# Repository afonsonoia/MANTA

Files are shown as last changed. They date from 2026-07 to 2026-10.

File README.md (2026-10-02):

# MANTA – Embedded AI & Vision-Guided Autonomous Flight Platform

<p align="center">
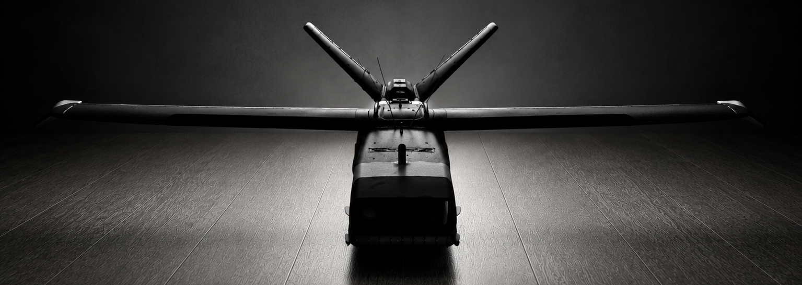
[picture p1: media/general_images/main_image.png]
MANTA Aircraft Platform
  
</p>

<p align="center">
  
  
  
  
  
  
</p>

**MANTA** is an experimental fixed-wing UAV research platform designed for investigating embedded computer vision, attitude stabilization, and autonomous navigation in GPS-denied environments.

Rather than relying on commercial black-box autopilots, MANTA is engineered from the ground up as an open, modular avionics architecture: combining low-level deterministic real-time control (ESP32) with high-level onboard perception and video recording (Raspberry Pi 3 A+ companion computer).

> **Origin of the Name**: *MANTA* is a regional term from Madeira Island, Portugal, designating the local population of the Common Buzzard (*Buteo buteo rothschildi*), a resident bird of prey known for soaring effortlessly across the island's steep oceanic mountains.

---

## In-Flight Validation & Onboard Camera Footage

MANTA has achieved fully stabilized flight under closed-loop fly-by-wire control with calibrated attitude PIDs, verified aerodynamic handling, and active onboard video recording.

The companion computer (**Raspberry Pi 3 A+**) flies onboard with a dedicated camera module, executing an autonomous power-loss-immune recording pipeline (`.mkv`) with sport shutter tuning to eliminate motor vibration artifacts and rolling shutter jello.

### Onboard Flight Video

<p align="center">
  <a href="https://www.youtube.com/watch?v=h6kUTQn7zuM&t=90s" target="_blank" rel="noopener noreferrer" title="Click to watch MANTA flight video on YouTube starting at 1:30 min">
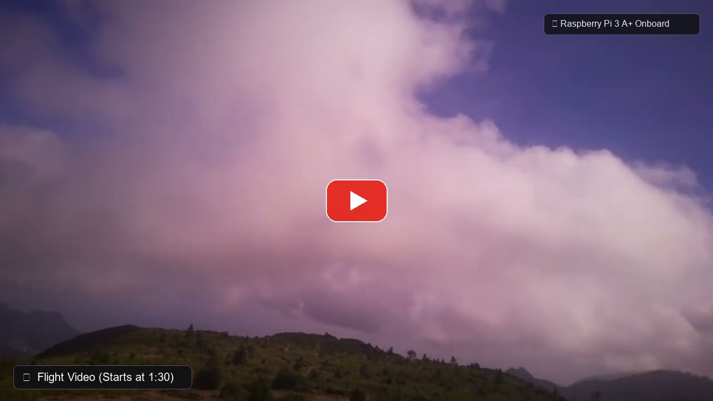
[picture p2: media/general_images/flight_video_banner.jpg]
MANTA Onboard Flight Footage (Click to Play from 1:30 min)
    
  </a>
  <br>
  <em>▶️ <b>Watch the flight video</b> — Aerial footage captured directly by the onboard Raspberry Pi 3 A+ camera during flight tests. <b><a href="https://www.youtube.com/watch?v=h6kUTQn7zuM&t=90s" target="_blank">Click here or on the image above to play on YouTube starting at 1:30 min</a></b>.</em>
</p>

### Pre-Flight Preparation & Avionics Checkout

<p align="center">
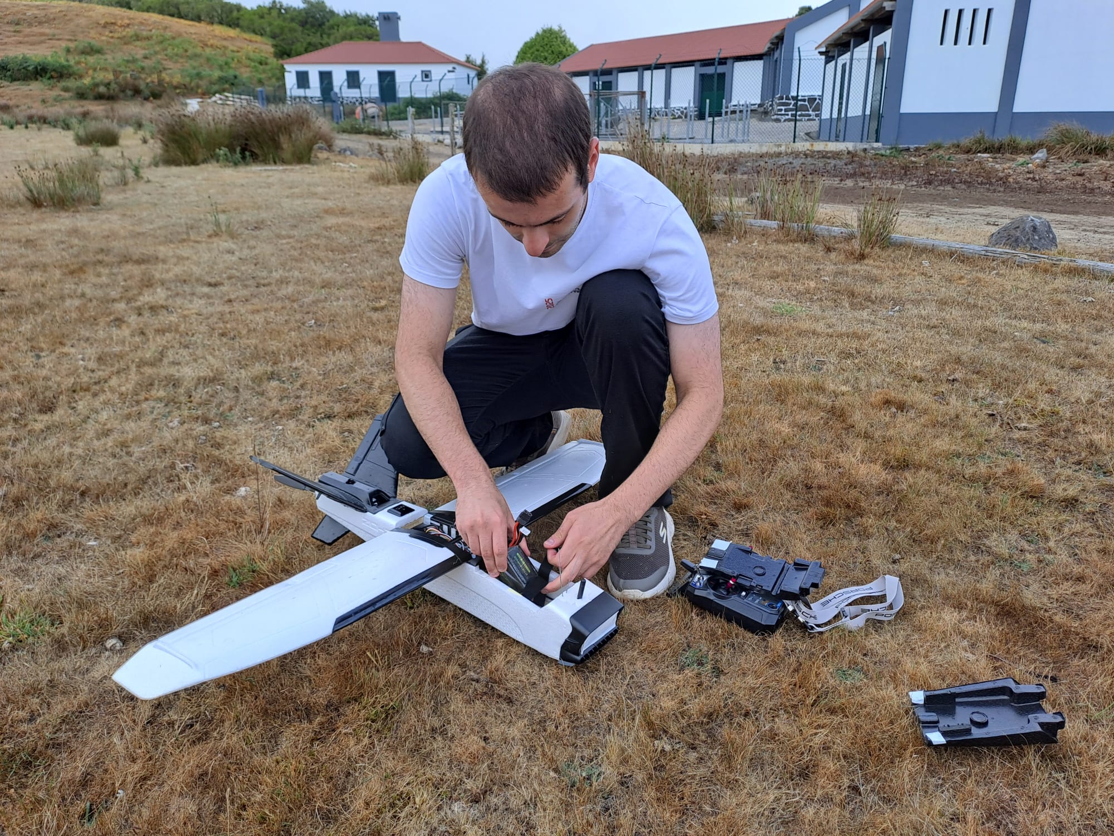
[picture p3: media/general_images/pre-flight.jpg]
Pre-Flight Avionics Check and Setup
  
  <br>
  <em>Pre-flight checkout at the flight field: LiPo battery installation, 6-axis IMU zeroing, radio link verification, and autonomous companion computer boot sequence before launch.</em>
</p>

During field operations, pre-flight checks verify the full avionics chain:
1. **Airframe & Propulsion**: 4S LiPo battery securement, Hobbywing Skywalker 40A V2 ESC throttle arming, and control horn linkage checks.
2. **IMU & Attitude Zeroing**: Static 6-axis MPU6050 accelerometer and gyroscope calibration with mounting offsets (+9.2° Pitch, +4.4° Roll).
3. **Control Surface Trims**: V-tail ruddervator and elevon zero-point verification across all 4 servos within calibrated hardware limits.
4. **LoRa Telemetry Handshake**: 20 Hz binary telemetry downlink reception and acoustic buzzer confirmation on the Ground Station ESP32.
5. **Companion Boot**: Autonomous transition of the Raspberry Pi 3 A+ into Field Mode with RF blocking and continuous video capture.

---

## Avionics & Embedded Hardware Architecture

MANTA uses a custom-manufactured dual-board shield architecture designed in KiCad, cleanly distributing high-current motor power and low-noise sensor signals while fitting into the airframe fuselage.

<p align="center">
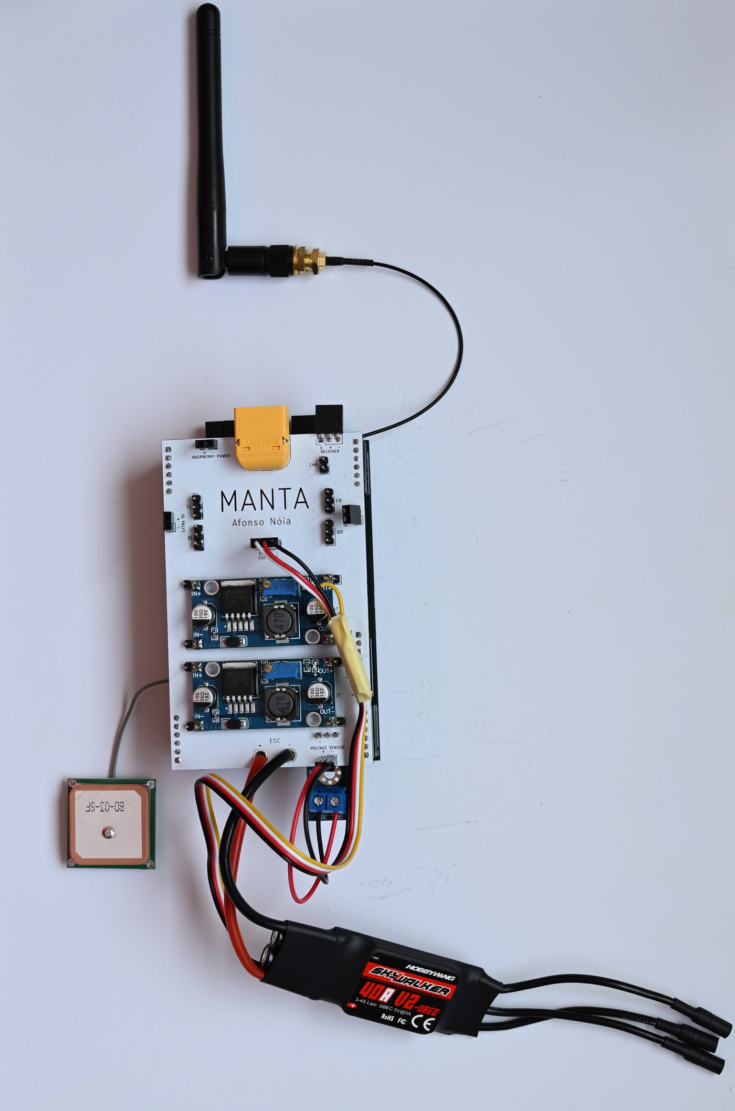
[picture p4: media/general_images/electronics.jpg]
MANTA Assembled Electronics Stack
  
  <br>
  <em>Complete assembled avionics stack: Custom dual-board PCB shield, ESP32 flight controller, LoRa 433 MHz RF link, Air530 GPS antenna, dual LM2596S switching buck converters, precision voltage divider, and Hobbywing Skywalker 40A V2-UBEC ESC.</em>
</p>

### Core Hardware Components

| Subsystem | Component | Role / Specification |
|---|---|---|
| **Flight Controller** | ESP32-WROOM-32 (240 MHz Dual-Core) | Real-time 100 Hz attitude estimation, RC receiver pulse decoding, PI-D control loops, V-tail servo mixing, and 20 Hz LoRa telemetry. |
| **Companion Computer** | Raspberry Pi 3 A+ (64-bit Quad-Core) | Camera management, high-bitrate in-flight video recording, visual place recognition (VPR), and future autonomous vision navigation. |
| **In-Flight Camera** | Sony IMX378-79 Sensor Module | High-resolution aerial video capture, 2x2 binned low-latency readout, and visual feature extraction. |
| **Inertial Measurement (IMU)** | MPU6050 (6-Axis Accel / Gyro) | High-rate attitude determination running Mahony AHRS quaternion fusion filter at 100 Hz. |
| **Barometric Altimeter** | BMP280 | Static pressure sensing, relative barometric altitude tracking, and vertical velocity estimation over I2C. |
| **RF Telemetry Link** | SX1278 LoRa Transceiver (433 MHz) | Long-range 20 Hz binary telemetry downlink (SF7, BW 250 kHz, CR 4/5, CRC16) streaming flight dynamics to the ground. |
| **Satellite Navigation** | Air530 Multi-GNSS Module | Global positioning reference, ground track velocity, and satellite constellation tracking over hardware UART. |
| **Electronic Speed Control (ESC)** | Hobbywing Skywalker 40A V2-UBEC | 3S–4S LiPo motor speed control with integrated 5V/5A switching BEC powering the avionics bus. |
| **Power Regulation** | Dual LM2596S DC-DC Regulators | Independent 5.1V / 3A power rails dedicated to the Raspberry Pi companion computer and servo bus, isolating control logic from servo voltage sag. |
| **Battery Monitoring** | Precision Calibrated Voltage Divider | Calibrated ADC sensing validated to within 0.062V of multimeter ground truth across 3S/4S voltage curves. |

### Custom Manufactured PCB Shields

<p align="center">
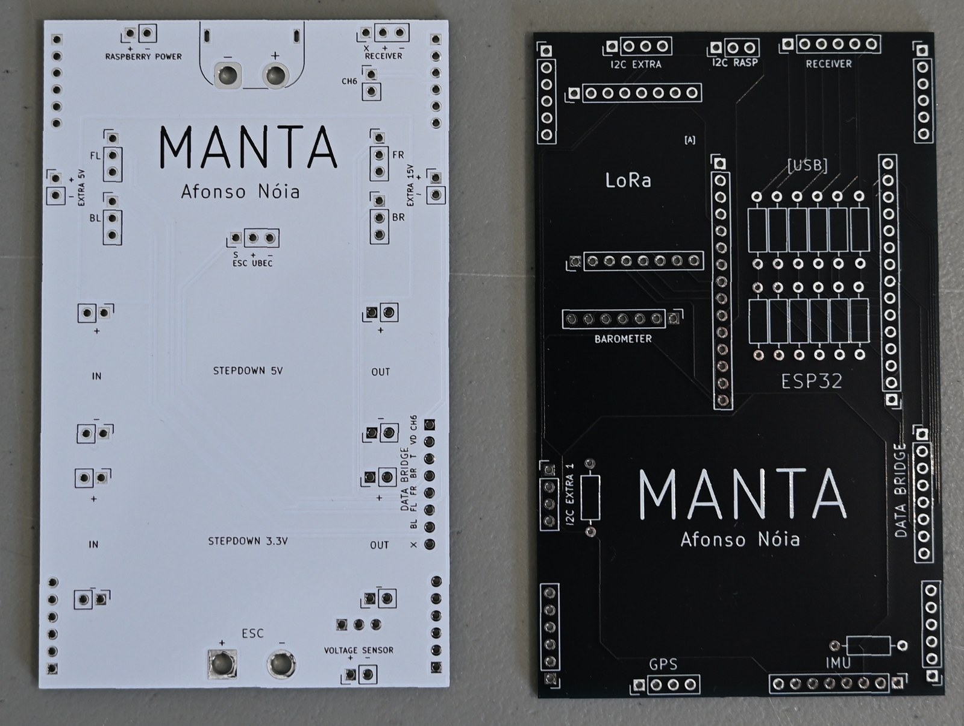
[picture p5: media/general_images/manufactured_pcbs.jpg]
Manufactured Physical PCBs
  
</p>

<p align="center">
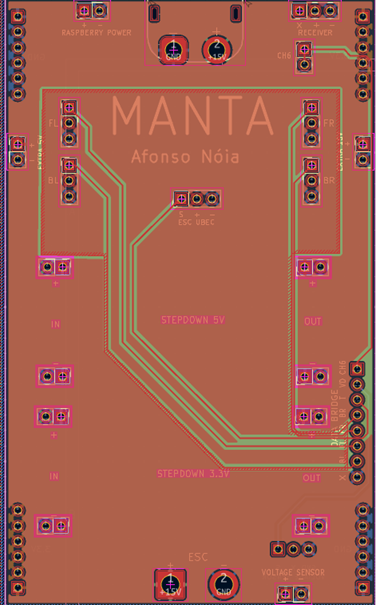
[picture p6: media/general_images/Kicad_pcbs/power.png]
PCB Power Routing
  
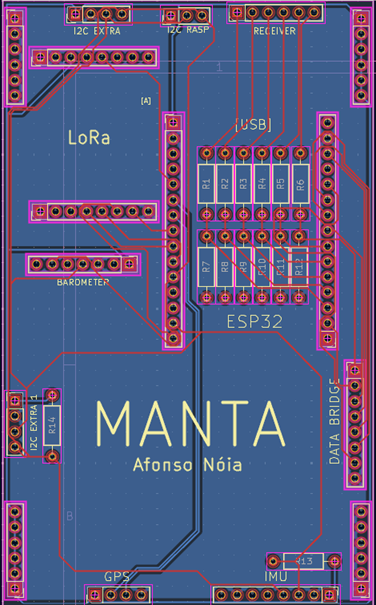
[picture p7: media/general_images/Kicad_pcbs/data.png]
PCB Data Routing
  
  <br>
  <em>KiCad Dual-Board Shield Layouts: Power Distribution Board & Data / Sensor Board</em>
</p>

- **Two-Board Architecture**: Separates noisy high-current traces (motor ESC, LiPo leads, buck regulators) on the Power Board from sensitive analog sensors (MPU6050, BMP280, LoRa SPI bus, RC receiver lines) on the Data Board.
- **Continuous Ground Pours**: Low-impedance ground returns and copper shielding prevent motor/ESC switching noise from coupling into the RF frontend or ADC measurements.

### Pinout & GPIO Mapping

```
RC Receiver Inputs:                  Servo & ESC Outputs:
  CH1 (Roll / Rollerons): Pin D39      Back Right (BR / V-Tail): Pin D13
  CH2 (Pitch / Elevator): Pin D34      Back Left  (BL / V-Tail): Pin D14
  CH3 (Throttle / ESC):   Pin D35      Front Right (FR / Flap):  Pin D27
  CH4 (Aux / Rudder):     Pin D32      Front Left  (FL / Flap):  Pin D26
  CH5 (Mode SWC + SWB):   Pin D33      Motor Throttle / ESC:     Pin D25

Buses & Peripherals:
  LoRa SX1278 (VSPI):     SCK=18, MISO=19, MOSI=23, CS=5, DIO0=4
  I2C Sensors (IMU+BMP):  SDA=21, SCL=22
  Air530 GNSS (UART2):    RX2=16, TX2=17
  Battery Voltage ADC:    Pin D36 (VP)
```

---

## Flight Control Architecture & Calibrated PIDs

MANTA utilizes a hybrid V-tail mixing scheme where Pitch is controlled by the rear ruddervators (BR/BL) and Roll is controlled by the front control surfaces (FR/FL), with elevator assist.

```mermaid
flowchart TD
    subgraph Inputs [Pilot & Sensor Inputs]
        RC[RC Receiver CH1-CH5]
        IMU[MPU6050 6-Axis IMU]
        BARO[BMP280 Barometer]
    end

    subgraph StateEst [Attitude Estimation]
        IMU --> Mahony[100 Hz Mahony AHRS Filter]
        Mahony --> Att[Pitch & Roll Euler Angles]
    end

    subgraph ControlCore [Flight Control Core]
        RC --> ModeSelect{Flight Mode Selector\nCH5 SWC + SWB}
        Att --> ModeSelect

        ModeSelect -->|Mode 1| M1[Manual Pitch + Roll Assist]
        ModeSelect -->|Mode 2| M2[FBW Pitch PI-D + FBW Roll PI-D]
        ModeSelect -->|Mode 3| M3[FBW Pitch PI-D + Adaptive Extremum Seeking Roll]

        SWB{Flaperons SWB} -->|Active| Flaps[20° Down Flaperon Governor]
    end

    subgraph Mixing [Actuator Mixer & Anti-Saturation]
        M1 & M2 & M3 --> Mixer[V-Tail & Wing Mixer]
        Flaps --> Mixer
        Mixer --> Headroom[Headroom Scaling & Anti-Saturation]
    end

    subgraph Outputs [Physical Actuators]
        Headroom --> Servos[BR / BL / FR / FL Servos + ESC]
    end
```

### Flight Modes (Transmitter CH5: SWC + SWB)

The pilot switches flight modes in real time via transmitter switches **SWC** (3-position mode switch) and **SWB** (2-position flaperon switch):

| SWC | SWB | CH5 PWM | Active Mode | Flaperons | Control Characteristics |
|:---:|:---:|:---:|:---:|:---:|:---|
| 1 | OFF | **1166 µs** | **Mode 1** | **OFF** | **Manual Pitch + Roll Assist**: Direct pilot pitch authority with active IMU bank angle attenuation and automatic wing leveling. |
| 2 | OFF | **1328 µs** | **Mode 2** | **OFF** | **FBW PI-D Auto-Level**: Closed-loop Pitch PI-D auto-leveling and Roll PI-D stabilization. |
| 3 | OFF | **1411 µs** | **Mode 3** | **OFF** | **FBW Adaptive**: Pitch PI-D leveling + Extremum Seeking adaptive roll PID tuning. |
| 1 | ON  | **1541 µs** | **Mode 1** | **ON**  | Manual Pitch + Roll Assist with **+20.0° DOWN Flaperons**. |
| 2 | ON  | **1825 µs** | **Mode 2** | **ON**  | FBW Pitch PI-D + Roll PI-D with **+20.0° DOWN Flaperons**. |
| 3 | ON  | **1942 µs** | **Mode 2** *(Auto)* | **ON**  | **Automatic Safety Demotion to Mode 2** + Flaperons (prevents adaptive gain corruption during approach). |

### Control Features & Safety Mechanisms

1. **Permanent Roll Assist (Mode 1)**:
   - Full ±20° pilot authority near wings level (0° roll).
   - Progressive linear bank angle attenuation up to 60°:
     $$\text{Max Roll Command} = 20^\circ \times \left(1 - \frac{|\text{Roll}|}{60^\circ}\right)$$
   - Active auto-recovery: If roll exceeds 60°, an automatic 5° opposite leveling bias is injected while retaining full pilot recovery command.
2. **Pitch PI-D Closed-Loop Control**:
   - Strictly negative feedback equation: $\text{pitchDiff} = -\text{constrain}(\text{pitchPidOut})$.
   - Anti-stall climb limit clamped to 25° ($K_p = 5.00$).
   - Anti-windup integrator ceiling limited to $\pm 100\,\mu\text{s}$ ($\pm 9.0^\circ$ of trim authority), guaranteeing 64% dynamic headroom for proportional and derivative action.
3. **Flaperons Approach Governor & Anti-Saturation**:
   - Deploys up to **+20.0° DOWN** ($\pm 222\,\mu\text{s}$) on front control surfaces (FR/FL) to dramatically increase lift coefficient ($C_L$) and drag ($C_D$) for slow, stable landings.
   - Smooth linear throttle governor between $1200\,\mu\text{s}$ (full deflection) and $1500\,\mu\text{s}$ (fully retracted).
   - **Headroom Scaling**: Pilot roll command maintains 100% priority. When roll commands approach mechanical limits, flaperon deflection is automatically scaled down (`flaperonHeadroom = 1.0 - |rollDiff| / anglePulseLimit`), preventing servo binding and maintaining roll control without clipping.

### Static Surface Calibration & Trims

All control surfaces operate strictly within the hardware safety span $[1000, 2000]\,\mu\text{s}$ centered around calibrated mechanical neutral points:

| Surface | Pin | Neutral PWM | Static Trim | Angular Span | Description |
|---|:---:|:---:|:---:|:---:|---|
| **BR (Back Right)** | D13 | **1478 µs** | $-2.0^\circ$ ($-22\,\mu\text{s}$) | $1200 - 1756\,\mu\text{s}$ | $+2.0^\circ$ UP nose-up compensation for level glide in manual mode. |
| **BL (Back Left)**  | D14 | **1633 µs** | $-12.0^\circ$ ($+133\,\mu\text{s}$) | $1355 - 1911\,\mu\text{s}$ | $+2.0^\circ$ UP inverted V-tail compensation. |
| **FR (Front Right)**| D27 | **1500 µs** | $0.0^\circ$ ($0\,\mu\text{s}$) | $1222 - 1778\,\mu\text{s}$ | True mechanical center. |
| **FL (Front Left)** | D26 | **1544 µs** | $+4.0^\circ$ ($+44\,\mu\text{s}$) | $1266 - 1822\,\mu\text{s}$ | Horn spline offset alignment defining flat wing zero. |

- **IMU Pitch Mounting Offset**: $+9.2^\circ$ (longitudinal leveling reference).
- **IMU Roll Mounting Offset**: $+4.4^\circ$ ($+1.9^\circ$ airframe bias $+ 2.5^\circ$ left-roll compensation for straight flight).

---

## Companion Computer & Video Pipeline (Raspberry Pi 3 A+)

The Raspberry Pi 3 A+ companion computer provides onboard vision processing and in-flight video capture:

```mermaid
flowchart LR
    Power[Power On Pi] --> BootService[manta-boot.service]
    BootService --> Check{Wi-Fi detected\n< 30 seconds?}

    Check -->|YES| DevMode[Bench / Dev Mode]
    DevMode --> GitPull[git pull]
    DevMode --> SSH[SSH & Wi-Fi Active]
    DevMode --> CamIdle[Camera Free for CV]

    Check -->|NO| FlightMode[Field / Flight Mode]
    FlightMode --> RFKill[rfkill: Block 2.4 GHz RF]
    FlightMode --> HDMIOff[Disable HDMI Circuitry]
    FlightMode --> AutoRec[Continuous .mkv Safe Recording]
```

### Autonomous Dual-Mode Boot Stack (`manta_boot.sh`)
- **Bench / Dev Mode (Wi-Fi Detected < 30s)**: Pi keeps Wi-Fi and SSH active, syncs codebase, and leaves the camera open for interactive computer vision development.
- **Field / Flight Mode (No Wi-Fi < 30s)**:
  - **RF Cutoff**: Disables Wi-Fi and Bluetooth (`rfkill block all`) to eliminate 2.4 GHz interference with the RC receiver and LoRa link while conserving battery power.
  - **HDMI Power-Down**: Shuts down the HDMI display subsystem (`vcgencmd display_power 0`), saving ~30 mA.
  - **Autonomous Safe Recording**: Launches `record_flight.sh` saving video directly to local storage.
- **Anti-Lockout Mechanism**: Multi-layer startup unblocking (`ExecStartPre=+`, NetworkManager re-activation, and interface scan) guarantees the Pi can reconnect to Wi-Fi whenever returning to the workshop.

### Power-Loss Immunity & Video Optimizations
- **Matroska (`.mkv`) Container**: Traditional MP4 files corrupt if power drops before the file header is finalized. MANTA records in Matroska with synchronous cluster flushing (`--flush`), ensuring video remains 100% playable right up to the exact moment the LiPo is disconnected upon landing.
- **Anti-Jello & Sport Shutter**: Uses 2x2 sensor pixel binning (halving sensor readout time), fast sport shutter exposure, manual focus locked to infinity, and temporal denoiser disabled to prevent motion blur and rolling shutter vibration skew.

---

## Ground Station & Telemetry Architecture

<p align="center">
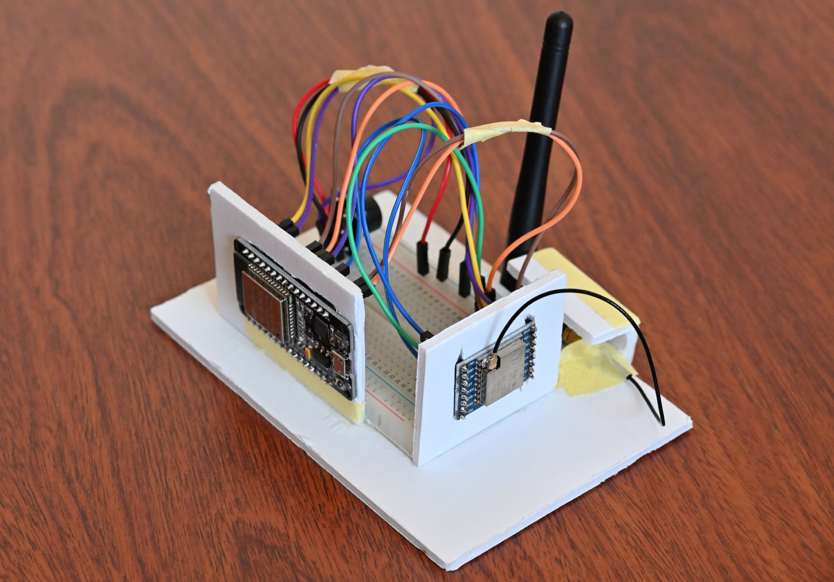
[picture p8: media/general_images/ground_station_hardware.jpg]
Ground Station Hardware
  
  <br>
  <em>Dedicated Ground Station hardware: ESP32 receiver, 433 MHz LoRa module, and piezo acoustic warning buzzer streaming live telemetry over USB to the PC Mission Planner.</em>
</p>

### Simplex Downlink Protocol
- **Aircraft Transmitter (Simplex TX)**: Transmits 20 Hz binary telemetry packets (61 bytes nominal / up to 74 bytes with GNSS and failsafe data) protected by CRC16. The aircraft has no LoRa receiver listening overhead, ensuring uninterrupted flight control loop execution.
- **Ground Station Receiver (Simplex RX)**: Receives LoRa packets and streams them over USB Serial (`115200 baud`) to the PC Ground Station application while driving an onboard piezo buzzer.
- **Acoustic Warning System**: Emits audible alerts for link loss, critical battery states, and distinct 700 ms confirmation beeps upon flight mode transitions (SWC/SWB).

### Ground Station Software Suite

| Tool | Path | Description |
|---|---|---|
| **Mission Planner** | [`Code/GROUND-STATION/MANTA_MISSION_PLANNER.py`](file:///c:/Users/Afonso%20Noia/PycharmProjects/BlueSky/Code/GROUND-STATION/MANTA_MISSION_PLANNER.py) | Full-featured PC HUD displaying artificial horizon, compass, altitude, battery gauge, RSSI/SNR signal metrics, GPS map tracking, and flight mode state. |
| **Flight Replay Simulator** | [`Code/GROUND-STATION/replay_flight_mission_planner.py`](file:///c:/Users/Afonso%20Noia/PycharmProjects/BlueSky/Code/GROUND-STATION/replay_flight_mission_planner.py) | Replays recorded flight logs (`flight_logs/manta_flight_XXXX.csv`) through the Mission Planner HUD for post-flight analysis. |
| **FPV Explorer** | [`Code/Computer Vision/manta_explorer.py`](file:///c:/Users/Afonso%20Noia/PycharmProjects/BlueSky/Code/Computer Vision/manta_explorer.py) | Desktop GUI for previewing, browsing, and inspecting in-flight camera videos captured by the Raspberry Pi. |
| **Video Retrieval** | [`Code/Computer Vision/download_videos.py`](file:///c:/Users/Afonso%20Noia/PycharmProjects/BlueSky/Code/Computer Vision/download_videos.py) | Automated tool for pulling flight recordings from the Raspberry Pi over SCP/SFTP. |
| **PID SysID Tuner** | [`Code/GROUND-STATION/tune_pid_sysid.py`](file:///c:/Users/Afonso%20Noia/PycharmProjects/BlueSky/Code/GROUND-STATION/tune_pid_sysid.py) | System identification and PID tuning tool using recorded flight telemetry. |

---

## Repository Structure

```
├── .agents/                        # Aircraft configuration, pin mapping & control rules
├── Code/
│   ├── Battery_Monitor/            # Battery voltage calibration and ESC logger GUI
│   ├── Computer Vision/
│   │   ├── demos/                  # Visual Place Recognition (VPR) MobileNet + KNN experiments
│   │   ├── Simulator/              # Python flight dynamics simulator & PID visualization
│   │   ├── convert_videos.py       # H.264 / MKV video converter & re-muxer
│   │   ├── download_videos.py      # Automated flight video downloader from Raspberry Pi
│   │   └── manta_explorer.py       # Desktop FPV video explorer and review GUI
│   ├── GROUND-STATION/
│   │   ├── include/ & src/         # ESP32 Ground Station receiver firmware (PlatformIO)
│   │   ├── MANTA_MISSION_PLANNER.py # PC HUD Ground Station & telemetry dashboard
│   │   ├── replay_flight_mission_planner.py # Post-flight telemetry replay tool
│   │   ├── telemetry_codec.py      # Python binary telemetry packet encoder/decoder
│   │   ├── telemetry_csv_logger.py # Asynchronous high-rate flight log recorder
│   │   └── tune_pid_sysid.py       # Telemetry-based PID tuning and SysID analyzer
│   ├── MANTA_ESP32/
│   │   ├── include/ & src/         # Main flight controller C++ firmware (PlatformIO)
│   │   │   ├── control.cpp         # 100 Hz PI-D, Roll Assist, Flaperons governor & mixer
│   │   │   ├── mpu6050.cpp         # Mahony AHRS quaternion attitude estimation
│   │   │   ├── receiver.cpp        # 5-channel RC pulse decoder & deadband filtering
│   │   │   ├── network.cpp         # 20 Hz binary LoRa telemetry transmission
│   │   │   ├── bmp280.cpp          # I2C barometric altitude & pressure tracking
│   │   │   └── gps.cpp             # Hardware UART GNSS parsing & auto-pin detection
│   │   └── platformio.ini          # ESP32 build configuration & dependencies
│   └── MANTA_PI/
│       ├── manta_boot.sh           # Autonomous dual-mode boot manager (Bench vs Flight)
│       ├── manta-boot.service      # Systemd boot service for Raspberry Pi
│       ├── record_flight.sh        # Power-loss safe in-flight video recording
│       └── stream_flight.sh        # Low-latency live video streaming script
├── Electronics/
│   ├── DATA/                       # KiCad PCB layout & schematic (Data / Sensor Board)
│   └── POWER/                      # KiCad PCB layout & schematic (Power Distribution Board)
├── media/
│   └── general_images/             # Flight banner, in-flight video thumbnail, hardware photos & PCB layouts
├── tests/                          # 171 automated CI/CD unit & integration tests
└── run_tests.py                    # Master CI/CD test runner
```

---

## CI/CD Test Suite & Verification

The codebase includes an extensive automated test suite covering firmware compilation, control kinematics, telemetry codecs, fail-safes, and analytical sensor accuracy:

```bash
python run_tests.py
```

```
============================================================================
                  MANTA AVIONICS CI/CD TEST SUITE RUNNER            
============================================================================
  SUCCESS: All 171 MANTA CI/CD tests PASSED cleanly! (53.82s)
  Categories Verified:
    [PASS] Firmware & Python Compilation (PlatformIO ESP32 & Ground Station)
    [PASS] Fly-By-Wire Control, PI-D & Kinematics
    [PASS] Simplex Telemetry Codec & Protocols (Fuzzing, Bit-Corruption Rejection)
    [PASS] Flight Safety, Failsafes & SysID Alignment
    [PASS] Sensor Calibration & Ground Truth Verification (Voltage error < 0.062V)
============================================================================
```

---

## Project Roadmap

### Phase 1: Hardware Proof-of-Concepts (POC)
- [x] Establish ESP32 communications with peripheral sensors (BMP280, LoRa, Voltage sensor).
- [x] Implement RC receiver pulse width reading and telemetry logs.
- [x] Establish initial LoRa communication between aircraft and ground station.
- [x] Set up lightweight visual place recognition experiments using aerial imagery databases.
- [x] Perform isolated bench tests for each sensor to ensure accuracy and data reliability.

### Phase 2: Airframe Assembly & Avionics Integration
- [x] Assemble the main airframe skeleton and mount propulsion/control surfaces.
- [x] Complete custom KiCad PCB schematics and dual-board layout routing.
- [x] Manufacture physical dual-board PCB shield architecture (Power & Data boards).
- [x] Validate power distribution, dual BEC outputs, and sensor bus continuity.
- [x] Experimentally calibrate battery voltage conversion against multimeter ground truth (< 0.062V error).
- [x] Mount core avionics and electronics on the airframe.
- [x] Conduct EMI testing ensuring motor/ESC switching noise does not disrupt GPS or LoRa RF link.
- [x] Deploy robust LoRa telemetry (20 Hz binary codec, non-blocking Ground Station logging).
- [x] Execute maiden field flights in manual mode to validate airframe aerodynamics and ground station link.

### Phase 3: Flight Control & Fly-By-Wire Stabilization
- [x] Integrate 6-axis MPU6050 Mahony AHRS quaternion sensor fusion (100 Hz) into ESP32 firmware.
- [x] Implement attitude-aware roll envelope protection and progressive bank angle limiting on RC Channel 5.
- [x] Implement and calibrate closed-loop PI-D controllers for Pitch (rear V-tail) and Roll (front surfaces).
- [x] Implement 20° flaperons approach governor with dynamic headroom anti-saturation scaling.
- [x] Conduct field flight tests to calibrate PIDs for smooth, wind-resistant fly-by-wire leveling.
- [x] Mount and integrate Raspberry Pi 3 A+ companion computer and onboard camera module.
- [x] Deploy autonomous dual-mode boot stack and power-loss-immune flight video recording (`.mkv`).
- [x] Validate closed-loop flight stability and record in-flight aerial footage.

### Phase 4: Autonomous Waypoint Navigation & Path-Planning
- [ ] Implement interactive trajectory planner in PC Ground Station UI to select waypoints on a map.
- [ ] Transmit pre-planned path coordinates from Mission Planner to aircraft over wireless link.
- [ ] Develop onboard navigation controller fusing GPS, BMP280 barometric altitude, and IMU data.
- [ ] Validate autonomous waypoint-to-waypoint navigation, altitude hold, heading lock, and fail-safe Return-to-Home (RTH).
- [ ] Execute autonomous field flight missions to verify trajectory accuracy and fail-safe reliability.

### Phase 5: Onboard Vision & Visual Place Recognition (VPR)
- [x] Design custom mount and install Raspberry Pi 3 A+ companion computer and camera module on airframe.
- [x] Execute onboard high-rate video logging and autonomous flight capture.
- [ ] Set up ESP32-to-Raspberry Pi high-speed serial communication protocol (UART / telemetry bridge).
- [ ] Deploy lightweight Visual Place Recognition (VPR) for image-based GPS-denied position estimation.
- [ ] Develop computer vision pipelines for visual horizon detection and landmark/mountain recognition.
- [ ] Test real-time visual perception and localization during autonomous flight.
- [ ] Perform comprehensive flight campaigns evaluating vision-based localization precision under real operational conditions.

---

## Authors & Acknowledgments

- **Afonso Nóia** — Aircraft design, custom PCB hardware, firmware development, fly-by-wire control algorithms, companion computer software, and flight testing.
- Platform development and field testing conducted on Madeira Island, Portugal.

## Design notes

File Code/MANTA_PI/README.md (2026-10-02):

# MANTA_PI — Companion Computer Software Stack

This folder contains the onboard software designed to run on the **Raspberry Pi 3 A+** with a **Sony IMX378-79** camera module on the MANTA UAV.

---

## 1. Autonomous Dual-Mode Boot Manager (`manta_boot.sh`)
Upon powering up the Raspberry Pi 3 A+, the [`manta-boot.service`](file:///c:/Users/Afonso%20Noia/PycharmProjects/BlueSky/Code/MANTA_PI/manta-boot.service) systemd unit automatically executes and inspects the environment for **30 seconds**:

```mermaid
flowchart TD
    Boot([Power Up Raspberry Pi]) --> CheckWiFi{Wi-Fi connected\nin < 30 seconds?}
    CheckWiFi -- YES --> ModeDev[DEVELOPMENT / BENCH MODE]
    CheckWiFi -- NO --> ModeFlight[FLIGHT / AUTONOMOUS MODE]

    subgraph ModeDev_Details [Development Mode]
        ModeDev --> Pull[Automatic git pull]
        Pull --> Ready[SSH active on Wi-Fi]
        Ready --> NoRecord[Camera Free / No Recording]
    end

    subgraph ModeFlight_Details [Flight Mode]
        ModeFlight --> KillRF[Disable Wi-Fi and Bluetooth - rfkill]
        KillRF --> KillHDMI[Disable HDMI to save battery]
        KillHDMI --> AutoRecord[Start Safe Recording in .mkv]
    end
```

### Scenario A — Wi-Fi Connected (< 30s): **Development / Bench Mode**
- The aircraft is on the workbench or near home connected to the local Wi-Fi network.
- The script detects connectivity, pulls the latest code (`git pull origin untested`).
- Wi-Fi and SSH remain active for ground development and live testing.
- **Does not start video recording**, leaving the camera available for live streaming or CV development.

### Scenario B — No Wi-Fi (30s Timeout): **Flight / Field Mode**
- The aircraft is powered on at the flight field without a known Wi-Fi network.
- After 30 seconds:
  1. **Full RF Cutoff**: Blocks Wi-Fi and Bluetooth (`rfkill block all`) to conserve power and eliminate 2.4 GHz interference with the RC receiver and LoRa telemetry link.
  2. **Energy Conservation**: Powers down the HDMI display output circuitry (`vcgencmd display_power 0`), saving ~30 mA.
  3. **Continuous Safe Recording**: Automatically executes `record_flight.sh` saving video in `.mkv` with zero risk of corruption if power is cut upon landing.

### Anti-Lockout Protection
- If the Pi previously entered Flight Mode, `systemd-rfkill` and `NetworkManager` persist that blocked state across reboots.
- To prevent an infinite lockout cycle, the system uses multi-layer active unblocking on startup:
  1. **Systemd Level (`ExecStartPre=+`)**: Unblocks `rfkill` with root permissions before user processes run.
  2. **NetworkManager Level**: Forces wireless networking and Wi-Fi radios active (`nmcli radio wifi on`).
  3. **Interface Level**: Sets all `wl*` interfaces to operational `UP` state.
  4. **Radio Level**: Triggers an active `rescan` for fast AP association.
  5. **Accurate Detection**: Validates connectivity via assigned IPv4 and carrier state to prevent false negatives when routers block ICMP pings.

---

## 2. Power-Loss Immunity
In fixed-wing UAV operations, LiPo power may disconnect abruptly during landing or impact.
- Standard MP4 indexes (`moov` atom) are only written upon clean closure; abrupt cuts corrupt the file.
- **Matroska (`.mkv`) + continuous `--flush`**:
  - Encodes each frame cluster independently.
  - Forces synchronous flush from RAM to SD card.
  - **Result**: Video remains 100% playable right up to the final millisecond before power disconnection.

---

## 3. Anti-Vibration & Anti-Jello Optimization (Motor Noise)
Electric motors induce high-frequency vibrations that cause rolling shutter skew ("jello"):
1. **Fast Readout (2x2 Pixel Binning 2028x1080)**: Cuts sensor readout time in half, reducing rolling shutter skew.
2. **Sport Exposure (`--exposure sport`)**: Prioritizes minimum shutter duration to eliminate motion blur. Fixed shutter speeds can also be set (e.g. `SHUTTER_US=2000` -> 1/500s).
3. **Temporal Denoise Disabled (`--denoise cdn_off`)**: Eliminates ghosting artifacts across vibration cycles.
4. **Hardware H.264 Acceleration (`bcm2835-codec`)**: On-chip encoding with low CPU load.
5. **Focus Lock at Infinity (`--autofocus-mode manual --lens-position 0.0`)**: Eliminates focus hunting caused by airframe vibrations.

---

## 4. Included Files

| File | Description |
|---|---|
| [`manta_boot.sh`](file:///c:/Users/Afonso%20Noia/PycharmProjects/BlueSky/Code/MANTA_PI/manta_boot.sh) | Autonomous dual-mode boot manager (30s Wi-Fi check -> Dev or Flight). |
| [`manta-boot.service`](file:///c:/Users/Afonso%20Noia/PycharmProjects/BlueSky/Code/MANTA_PI/manta-boot.service) | Systemd unit file for automatic system startup execution. |
| [`record_flight.sh`](file:///c:/Users/Afonso%20Noia/PycharmProjects/BlueSky/Code/MANTA_PI/record_flight.sh) | Shell script for power-loss safe flight video recording. |
| [`record_flight.py`](file:///c:/Users/Afonso%20Noia/PycharmProjects/BlueSky/Code/MANTA_PI/record_flight.py) | Python CLI controller for video recording (`--fps`, `--shutter`, `--duration`). |
| [`stream_flight.sh`](file:///c:/Users/Afonso%20Noia/PycharmProjects/BlueSky/Code/MANTA_PI/stream_flight.sh) | Low-latency live FPV video stream script. |

---

## 5. Enabling the Boot Service on Raspberry Pi

```bash
sudo cp /home/pc/MANTA/Code/MANTA_PI/manta-boot.service /etc/systemd/system/
sudo systemctl daemon-reload
sudo systemctl enable manta-boot.service
```

To view boot logs:
```bash
journalctl -u manta-boot.service -n 50
```

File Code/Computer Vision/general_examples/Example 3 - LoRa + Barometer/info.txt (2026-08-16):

RSSI Value,Signal Quality,What to Expect
-30 dBm to -50 dBm,Excellent,Devices are in the same room or very close.
-50 dBm to -80 dBm,Very Good,"Stable connection, ideal for indoor environments with walls."
-80 dBm to -100 dBm,Good / Medium,Typical medium-range signal (a few blocks away).
-100 dBm to -120 dBm,Weak,Approaching limit. Packet error rate may increase.
-120 dBm to -140 dBm,Critical Limit,"Where LoRa excels. Other wireless technologies would drop, but LoRa still receives (especially with higher SF)."

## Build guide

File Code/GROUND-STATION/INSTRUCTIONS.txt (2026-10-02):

================================================================
          MANTA GROUND STATION - QUICK START GUIDE
================================================================

1. INSTALL PYTHON DEPENDENCIES:
   In your terminal / command prompt, run:
   pip install -r requirements.txt

2. PREREQUISITES:
   - Have Mission Planner installed (optional, but recommended for HUD and MAVLink).
   - Connect Ground Station ESP32 via USB (ensure drivers are installed, e.g. CH340 / CP210x).

3. EXECUTE:
   python MANTA_MISSION_PLANNER.py

   (To specify a COM port manually:)
   python MANTA_MISSION_PLANNER.py --port COM4

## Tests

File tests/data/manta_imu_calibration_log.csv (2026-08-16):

record_number | timestamp_s | pitch_deg | roll_deg | altitude_m | rssi_dbm | snr_db
1 | 0.1 | -0.1 | 0.1 | 0.5 | -35 | 10.2
2 | 0.15 | -0.1 | 0.1 | 0.5 | -34 | 9.8
3 | 0.2 | -0.1 | 0.1 | 0.5 | -35 | 11.0
4 | 0.23 | -0.1 | 0.1 | 0.5 | -34 | 10.5
5 | 0.28 | -0.1 | 0.1 | 0.5 | -35 | 10.5
6 | 0.33 | -0.1 | 0.1 | 0.5 | -35 | 10.2
7 | 0.38 | -0.1 | 0.1 | 0.5 | -35 | 10.0
8 | 0.43 | -0.1 | 0.1 | 0.5 | -35 | 10.0
9 | 0.48 | -0.1 | 0.2 | 0.5 | -34 | 10.8
10 | 0.53 | -0.1 | 0.1 | 0.5 | -35 | 10.2
11 | 0.58 | -0.1 | 0.2 | 0.5 | -35 | 10.8
12 | 0.63 | -0.1 | 0.2 | 0.5 | -35 | 10.8
13 | 0.68 | -0.1 | 0.1 | 0.5 | -35 | 10.0
14 | 0.78 | -0.1 | 0.1 | 0.5 | -34 | 10.5
15 | 0.83 | -0.1 | 0.1 | 0.5 | -34 | 10.5
16 | 0.83 | -0.1 | 0.1 | 0.5 | -35 | 10.8
17 | 0.93 | -0.1 | 0.1 | 0.5 | -35 | 10.2
18 | 0.98 | -0.1 | 0.1 | 0.5 | -35 | 9.8
19 | 1.03 | -0.1 | 0.1 | 0.5 | -35 | 10.2
20 | 1.16 | -0.1 | 0.1 | 0.5 | -35 | 10.0
21 | 1.16 | -0.1 | 0.1 | 0.5 | -35 | 10.8
22 | 1.18 | -0.1 | 0.1 | 0.5 | -35 | 10.8
23 | 1.28 | -0.1 | 0.1 | 0.5 | -35 | 10.5
24 | 1.33 | -0.1 | 0.1 | 0.5 | -35 | 11.2
25 | 1.38 | -0.1 | 0.1 | 0.5 | -35 | 9.8
26 | 1.53 | -0.1 | 0.1 | 0.5 | -35 | 10.5
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

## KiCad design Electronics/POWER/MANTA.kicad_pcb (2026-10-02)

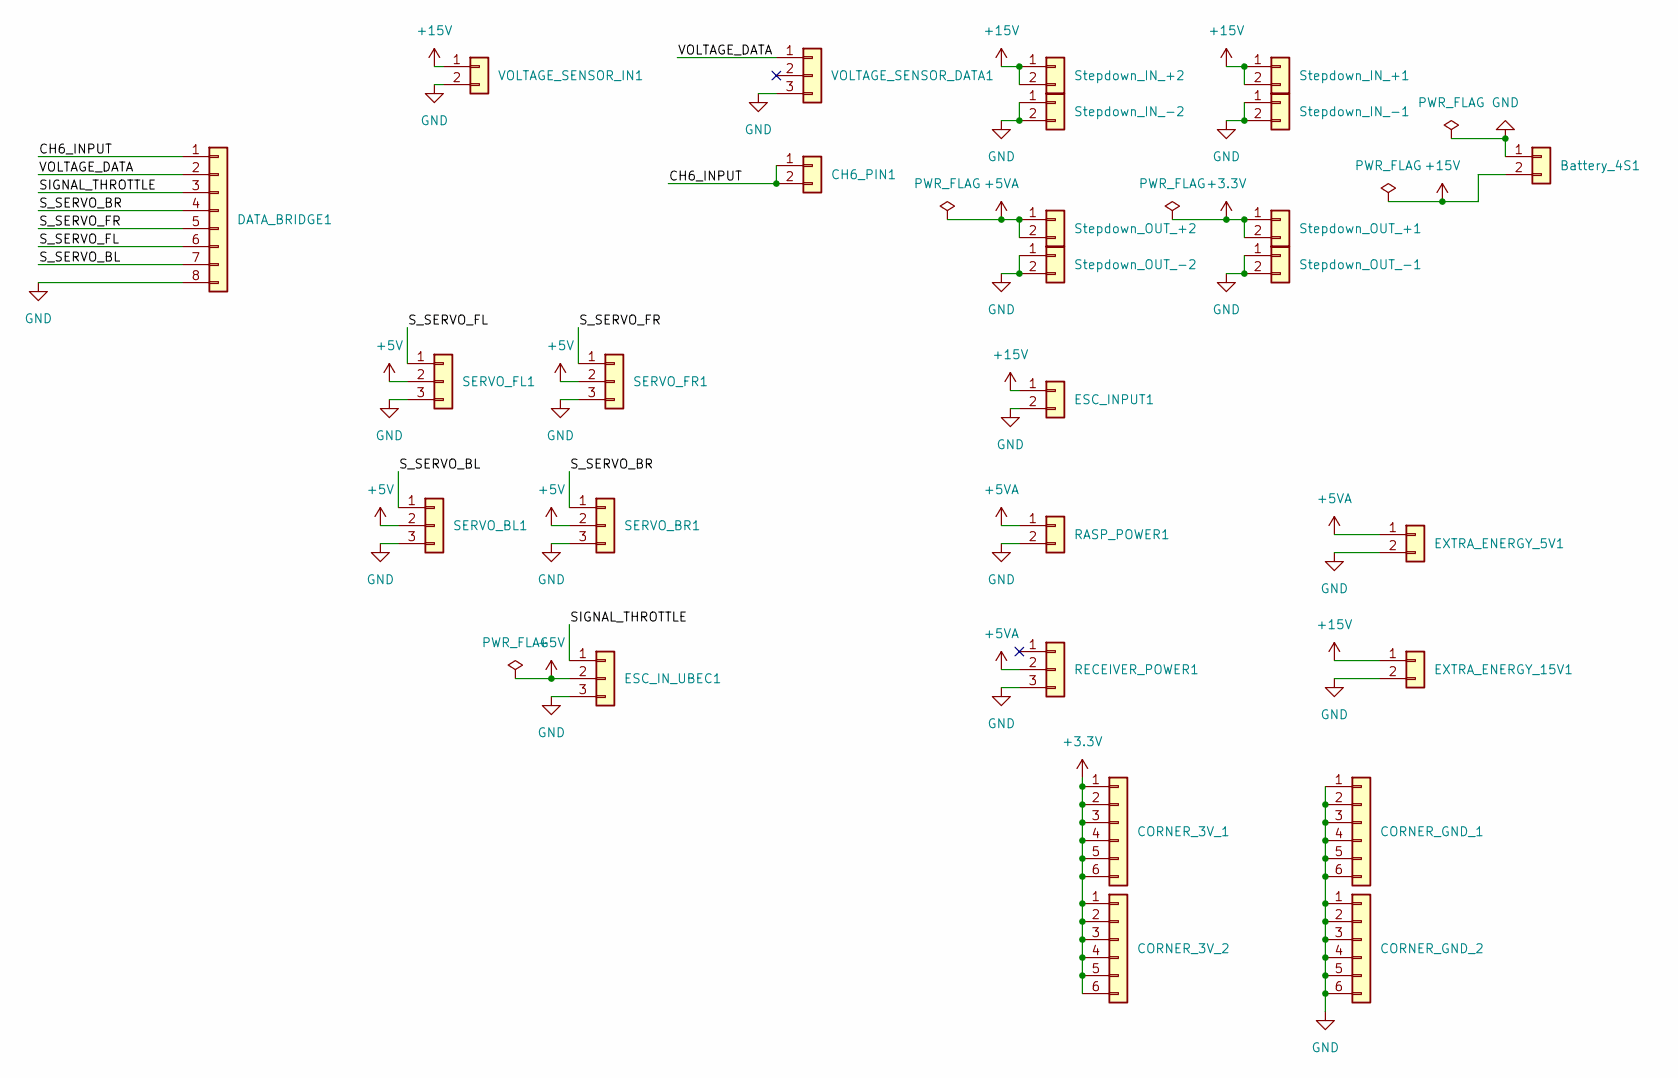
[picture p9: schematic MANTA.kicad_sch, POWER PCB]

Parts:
Battery_4S1: Conn_01x02; AMASS_XT60PW-M_1x02_P7.20mm_Horizontal
CH6_PIN1: Conn_01x02; PinHeader_1x02_P2.54mm_Vertical
CORNER_3V_1, CORNER_3V_2: Conn_01x06; PinHeader_1x06_P2.54mm_Vertical
CORNER_GND_1, CORNER_GND_2: Conn_01x06; PinHeader_1x06_P2.54mm_Vertical
DATA_BRIDGE1: Conn_01x08; PinHeader_1x08_P2.54mm_Vertical
ESC_INPUT1: SolderWire-2.5sqmm_1x02_P8.8mm_D2.4mm_OD4.4mm
ESC_IN_UBEC1: Conn_01x03; PinHeader_1x03_P2.54mm_Vertical
EXTRA_ENERGY_5V1, EXTRA_ENERGY_15V1: Conn_01x02; PinHeader_1x02_P2.54mm_Vertical
RASP_POWER1: Conn_01x02; PinHeader_1x02_P2.54mm_Vertical
RECEIVER_POWER1: Conn_01x03; PinHeader_1x03_P2.54mm_Vertical
SERVO_BL1: Conn_01x03; PinHeader_1x03_P2.54mm_Vertical
SERVO_BR1: Conn_01x03; PinHeader_1x03_P2.54mm_Vertical
SERVO_FL1: Conn_01x03; PinHeader_1x03_P2.54mm_Vertical
SERVO_FR1: Conn_01x03; PinHeader_1x03_P2.54mm_Vertical
Stepdown_IN_+1, Stepdown_IN_+2: Conn_01x02; PinHeader_1x02_P2.54mm_Vertical
Stepdown_IN_-1, Stepdown_IN_-2: Conn_01x02; PinHeader_1x02_P2.54mm_Vertical
Stepdown_OUT_+1, Stepdown_OUT_+2: Conn_01x02; PinHeader_1x02_P2.54mm_Vertical
Stepdown_OUT_-1, Stepdown_OUT_-2: Conn_01x02; PinHeader_1x02_P2.54mm_Vertical
VOLTAGE_SENSOR_DATA1: Conn_01x03; PinHeader_1x03_P2.54mm_Vertical
VOLTAGE_SENSOR_IN1: PinHeader_1x02_P2.54mm_Vertical

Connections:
+3.3V: CORNER_3V_1.1, CORNER_3V_1.2, CORNER_3V_1.3, CORNER_3V_1.4, CORNER_3V_1.5, CORNER_3V_1.6, CORNER_3V_2.1, CORNER_3V_2.2, CORNER_3V_2.3, CORNER_3V_2.4, CORNER_3V_2.5, CORNER_3V_2.6, Stepdown_OUT_+1.1, Stepdown_OUT_+1.2
+5V: ESC_IN_UBEC1.2, SERVO_BL1.2, SERVO_BR1.2, SERVO_FL1.2, SERVO_FR1.2
+5VA: EXTRA_ENERGY_5V1.1, RASP_POWER1.1, RECEIVER_POWER1.2, Stepdown_OUT_+2.1, Stepdown_OUT_+2.2
+15V: Battery_4S1.2, ESC_INPUT1.1, EXTRA_ENERGY_15V1.1, Stepdown_IN_+1.1, Stepdown_IN_+1.2, Stepdown_IN_+2.1, Stepdown_IN_+2.2, VOLTAGE_SENSOR_IN1.1
/CH6_INPUT: CH6_PIN1.1, CH6_PIN1.2, DATA_BRIDGE1.1
/SIGNAL_THROTTLE: DATA_BRIDGE1.3, ESC_IN_UBEC1.1
/S_SERVO_BL: DATA_BRIDGE1.7, SERVO_BL1.1
/S_SERVO_BR: DATA_BRIDGE1.4, SERVO_BR1.1
/S_SERVO_FL: DATA_BRIDGE1.6, SERVO_FL1.1
/S_SERVO_FR: DATA_BRIDGE1.5, SERVO_FR1.1
/VOLTAGE_DATA: DATA_BRIDGE1.2, VOLTAGE_SENSOR_DATA1.1
GND: Battery_4S1.1, CORNER_GND_1.1, CORNER_GND_1.2, CORNER_GND_1.3, CORNER_GND_1.4, CORNER_GND_1.5, CORNER_GND_1.6, CORNER_GND_2.1, CORNER_GND_2.2, CORNER_GND_2.3, CORNER_GND_2.4, CORNER_GND_2.5, CORNER_GND_2.6, DATA_BRIDGE1.8, ESC_INPUT1.2, ESC_IN_UBEC1.3, EXTRA_ENERGY_5V1.2, EXTRA_ENERGY_15V1.2, RASP_POWER1.2, RECEIVER_POWER1.3, SERVO_BL1.3, SERVO_BR1.3, SERVO_FL1.3, SERVO_FR1.3, Stepdown_IN_-1.1, Stepdown_IN_-1.2, Stepdown_IN_-2.1, Stepdown_IN_-2.2, Stepdown_OUT_-1.1, Stepdown_OUT_-1.2, Stepdown_OUT_-2.1, Stepdown_OUT_-2.2, VOLTAGE_SENSOR_DATA1.3, VOLTAGE_SENSOR_IN1.2

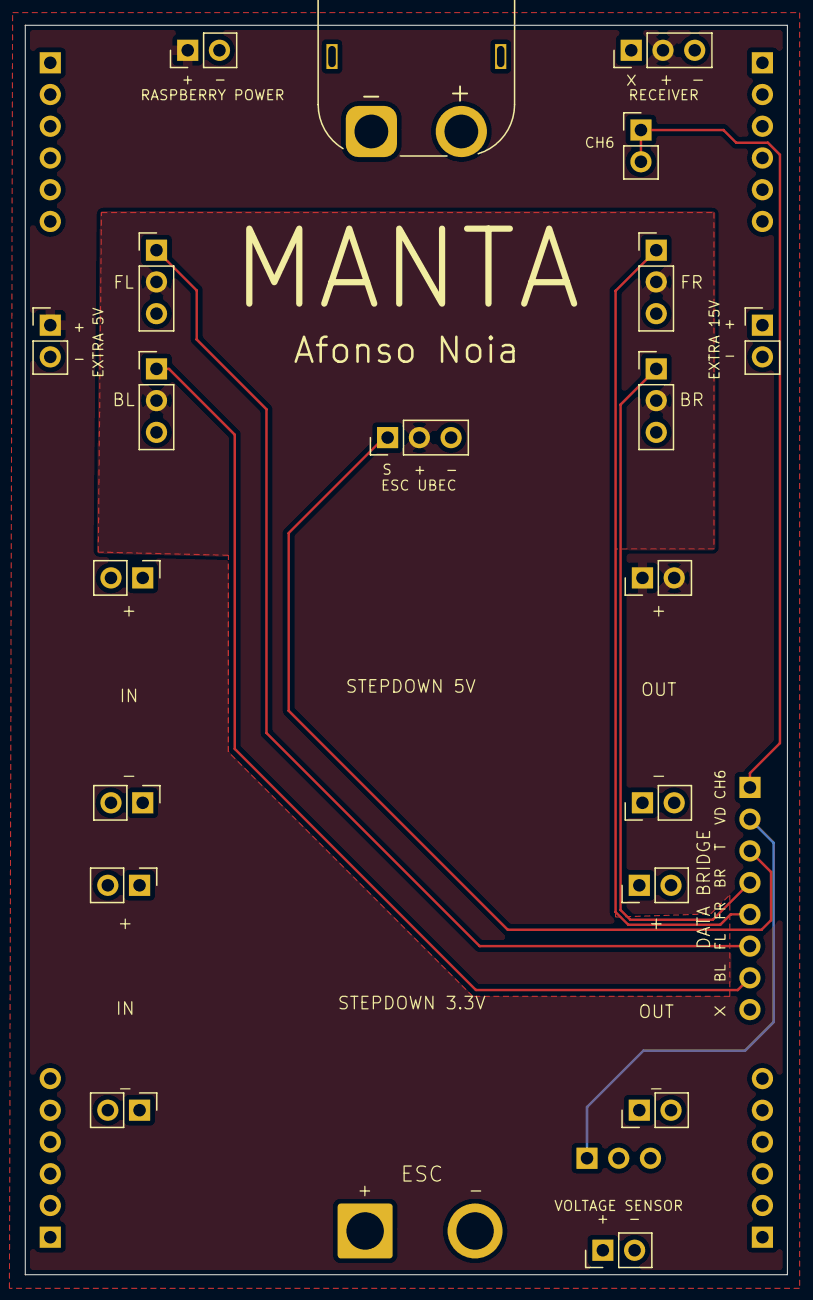
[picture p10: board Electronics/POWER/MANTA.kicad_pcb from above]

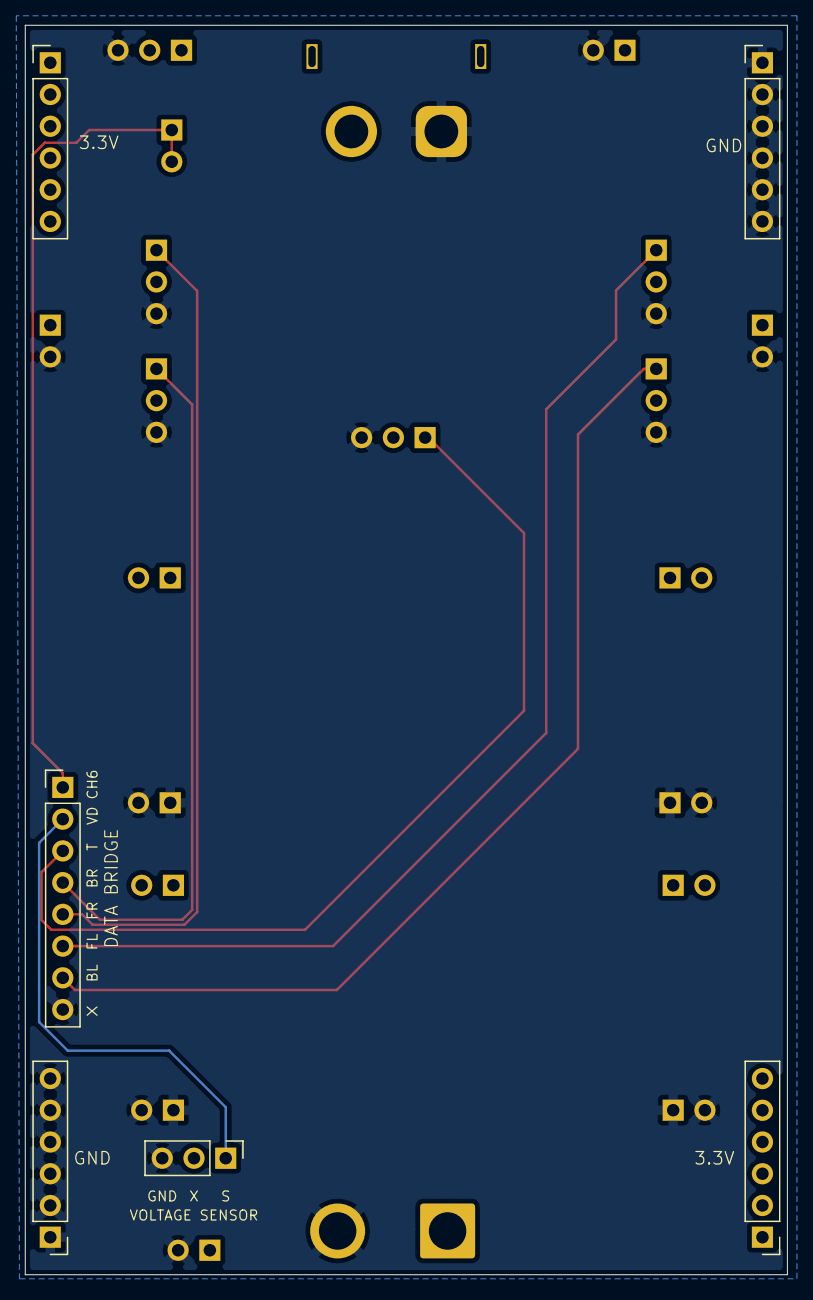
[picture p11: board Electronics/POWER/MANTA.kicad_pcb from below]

Board: 4 copper layers, 61.0 x 100.0 mm, 27 parts (6 on the bottom side), 12 nets.

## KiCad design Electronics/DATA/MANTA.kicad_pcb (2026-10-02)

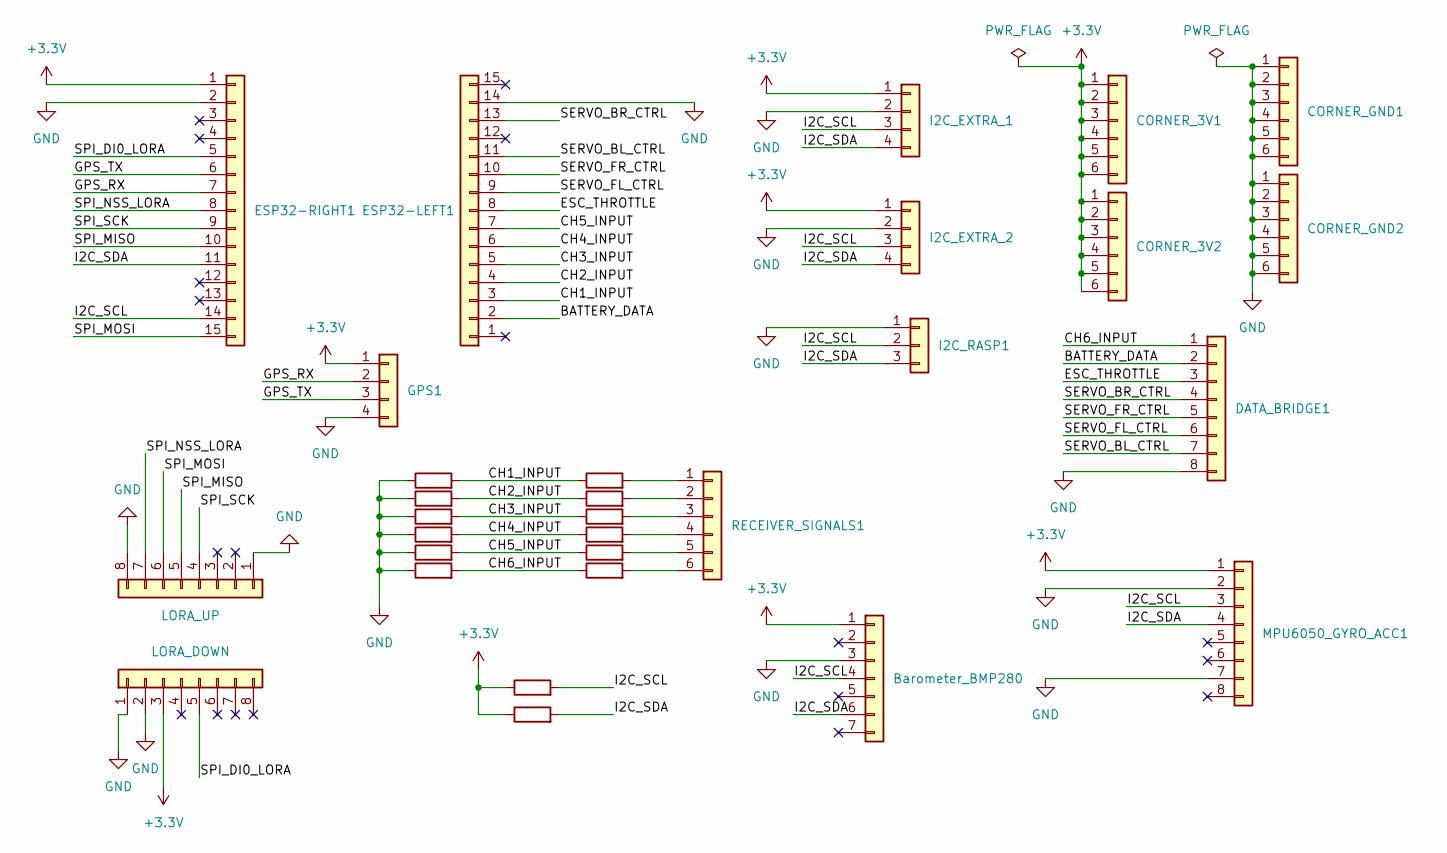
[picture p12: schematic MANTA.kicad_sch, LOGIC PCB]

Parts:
Barometer_BMP280: Conn_01x07; PinHeader_1x07_P2.54mm_Vertical
CORNER_3V1, CORNER_3V2: Conn_01x06; PinHeader_1x06_P2.54mm_Vertical
CORNER_GND1, CORNER_GND2: Conn_01x06; PinHeader_1x06_P2.54mm_Vertical
DATA_BRIDGE1: Conn_01x08; PinHeader_1x08_P2.54mm_Vertical
ESP32-LEFT1, ESP32-RIGHT1: Conn_01x15; PinHeader_1x15_P2.54mm_Vertical
GPS1: Conn_01x04; PinHeader_1x04_P2.54mm_Vertical
I2C_EXTRA_1, I2C_EXTRA_2: Conn_01x04; PinHeader_1x04_P2.54mm_Vertical
I2C_RASP1: Conn_01x03; PinHeader_1x03_P2.54mm_Vertical
J1: LORA_UP; PinHeader_1x08_P2.54mm_Vertical
J2: LORA_DOWN; PinHeader_1x08_P2.54mm_Vertical
MPU6050_GYRO_ACC1: Conn_01x08; PinHeader_1x08_P2.54mm_Vertical
R1, R2, R3, R4, R5, R6: 1k; R_Axial_DIN0207_L6.3mm_D2.5mm_P10.16mm_Horizontal
R7, R8, R9, R10, R11, R12: 2k; R_Axial_DIN0207_L6.3mm_D2.5mm_P10.16mm_Horizontal
R13, R14: 10k; R_Axial_DIN0207_L6.3mm_D2.5mm_P10.16mm_Horizontal
RECEIVER_SIGNALS1: Conn_01x06; PinHeader_1x06_P2.54mm_Vertical

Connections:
+3.3V: Barometer_BMP280.1, CORNER_3V1.1, CORNER_3V1.2, CORNER_3V1.3, CORNER_3V1.4, CORNER_3V1.5, CORNER_3V1.6, CORNER_3V2.1, CORNER_3V2.2, CORNER_3V2.3, CORNER_3V2.4, CORNER_3V2.5, CORNER_3V2.6, ESP32-RIGHT1.1, GPS1.1, I2C_EXTRA_1.1, I2C_EXTRA_2.1, J2.3, MPU6050_GYRO_ACC1.1, R13.1, R14.1
/BATTERY_DATA: DATA_BRIDGE1.2, ESP32-LEFT1.2
/CH1_INPUT: ESP32-LEFT1.3, R1.1, R7.2
/CH2_INPUT: ESP32-LEFT1.4, R2.1, R8.2
/CH3_INPUT: ESP32-LEFT1.5, R3.1, R9.2
/CH4_INPUT: ESP32-LEFT1.6, R4.1, R10.2
/CH5_INPUT: ESP32-LEFT1.7, R5.1, R11.2
/CH6_INPUT: DATA_BRIDGE1.1, R6.1, R12.2
/ESC_THROTTLE: DATA_BRIDGE1.3, ESP32-LEFT1.8
/GPS_RX: ESP32-RIGHT1.7, GPS1.2
/GPS_TX: ESP32-RIGHT1.6, GPS1.3
/I2C_SCL: Barometer_BMP280.4, ESP32-RIGHT1.14, I2C_EXTRA_1.3, I2C_EXTRA_2.3, I2C_RASP1.2, MPU6050_GYRO_ACC1.3, R13.2
/I2C_SDA: Barometer_BMP280.6, ESP32-RIGHT1.11, I2C_EXTRA_1.4, I2C_EXTRA_2.4, I2C_RASP1.3, MPU6050_GYRO_ACC1.4, R14.2
/SERVO_BL_CTRL: DATA_BRIDGE1.7, ESP32-LEFT1.11
/SERVO_BR_CTRL: DATA_BRIDGE1.4, ESP32-LEFT1.13
/SERVO_FL_CTRL: DATA_BRIDGE1.6, ESP32-LEFT1.9
/SERVO_FR_CTRL: DATA_BRIDGE1.5, ESP32-LEFT1.10
/SPI_DI0_LORA: ESP32-RIGHT1.5, J2.5
/SPI_MISO: ESP32-RIGHT1.10, J1.5
/SPI_MOSI: ESP32-RIGHT1.15, J1.6
/SPI_NSS_LORA: ESP32-RIGHT1.8, J1.7
/SPI_SCK: ESP32-RIGHT1.9, J1.4
GND: Barometer_BMP280.3, CORNER_GND1.1, CORNER_GND1.2, CORNER_GND1.3, CORNER_GND1.4, CORNER_GND1.5, CORNER_GND1.6, CORNER_GND2.1, CORNER_GND2.2, CORNER_GND2.3, CORNER_GND2.4, CORNER_GND2.5, CORNER_GND2.6, DATA_BRIDGE1.8, ESP32-LEFT1.14, ESP32-RIGHT1.2, GPS1.4, I2C_EXTRA_1.2, I2C_EXTRA_2.2, I2C_RASP1.1, J1.1, J1.8, J2.1, J2.2, MPU6050_GYRO_ACC1.2, MPU6050_GYRO_ACC1.7, R7.1, R8.1, R9.1, R10.1, R11.1, R12.1
unnamed: R1.2, RECEIVER_SIGNALS1.1
unnamed: R2.2, RECEIVER_SIGNALS1.2
unnamed: R3.2, RECEIVER_SIGNALS1.3
unnamed: R4.2, RECEIVER_SIGNALS1.4
unnamed: R5.2, RECEIVER_SIGNALS1.5
unnamed: R6.2, RECEIVER_SIGNALS1.6

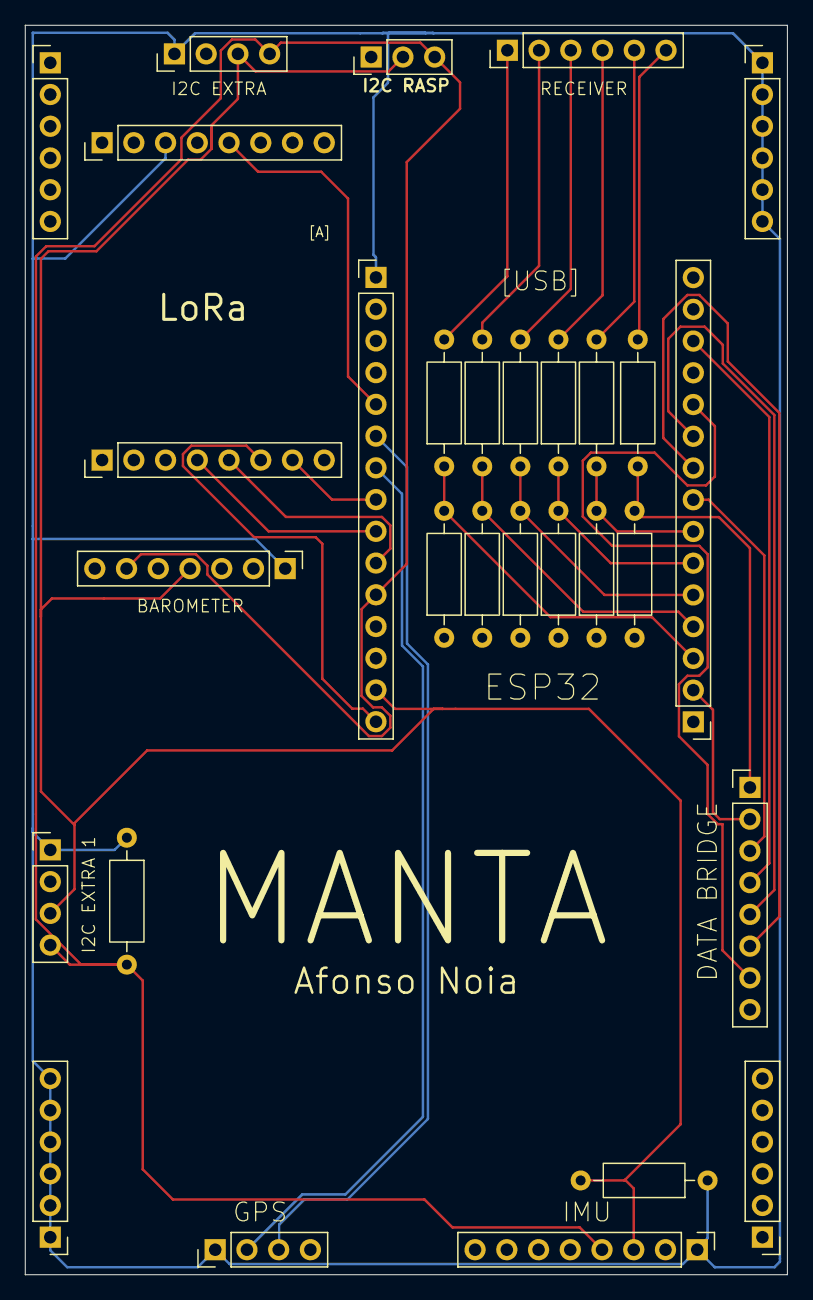
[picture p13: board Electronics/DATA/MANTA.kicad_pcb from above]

Board: 2 copper layers, 61.0 x 100.0 mm, 30 parts (0 on the bottom side), 29 nets.

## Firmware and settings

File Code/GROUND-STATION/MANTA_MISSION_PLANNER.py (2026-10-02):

import serial
import serial.tools.list_ports
import time
import os
import math
import re
import json
import subprocess
import socket
import queue
import threading
import sys
import csv
from collections import deque

try:
    from pymavlink import mavutil
    HAS_PYMAVLINK = True
except ImportError:
    HAS_PYMAVLINK = False

from telemetry_codec import decode_telemetry, encode_telemetry, decode_ch5_mode, PACKET_SIZE, SUPPORTED_PACKET_SIZES, SUPPORTED_PACKET_SIZES_DESC

# Config
DEFAULT_BAUD = 115200
_SCRIPT_DIR = os.path.dirname(os.path.abspath(__file__))
LOG_DIR = os.path.join(_SCRIPT_DIR, 'flight_logs')
_ROOT_DIR = os.path.abspath(os.path.join(_SCRIPT_DIR, '..', '..'))
if os.path.exists(os.path.join(_ROOT_DIR, 'imu_calibration.json')):
    CALIB_FILE = os.path.join(_ROOT_DIR, 'imu_calibration.json')
elif os.path.exists('imu_calibration.json'):
    CALIB_FILE = os.path.abspath('imu_calibration.json')
else:
    CALIB_FILE = os.path.join(_ROOT_DIR, 'imu_calibration.json')

def get_next_flight_log_filename(log_dir=None):
    """Scans flight_logs/ directory recursively and returns the next sequential flight log CSV filename."""
    if log_dir is None:
        log_dir = LOG_DIR
    os.makedirs(log_dir, exist_ok=True)
    
    max_idx = 0
    pattern = re.compile(r'manta_flight_(\d+)', re.IGNORECASE)
    for root, _, files in os.walk(log_dir):
        for fname in files:
            match = pattern.search(fname)
            if match:
                try:
                    idx = int(match.group(1))
                    if idx > max_idx:
                        max_idx = idx
                except ValueError:
                    pass

    next_idx = max_idx + 1
    timestamp_str = time.strftime("%Y%m%d_%H%M%S")
    filename = f"manta_flight_{next_idx:04d}_{timestamp_str}.csv"
    return os.path.join(log_dir, filename)

# Global state
active_serial_conn = None
last_rssi = None
last_snr = None
latest_estimated_voltage = 12.50
battery_voltage_history = deque(maxlen=20)

def calculate_battery_pct(voltage: float) -> int:
    if voltage <= 0.0:
        return 0
    if voltage > 13.0:
        # 4S LiPo: 13.6V (0%) to 16.8V (100%)
        return int(max(0, min(100, (voltage - 13.6) / (16.8 - 13.6) * 100)))
    else:
        # 3S LiPo: 10.2V (0%) to 12.6V (100%)
        return int(max(0, min(100, (voltage - 10.2) / (12.6 - 10.2) * 100)))

# Current IMU, GPS & Baro state
latest_pitch = 0.0
latest_roll = 0.0
latest_yaw = 0.0
latest_ax = 0
latest_ay = 0
latest_az = 0
latest_gx = 0
latest_gy = 0
latest_gz = 0
latest_ax_g = 0.0
latest_ay_g = 0.0
latest_az_g = 0.0
latest_total_accel_g = 1.0
latest_lat = 0.0
latest_lon = 0.0
latest_alt = 0.0
latest_temp = 25.0
latest_satellites = 0
latest_fix_type = 0
pitch_offset = 0.0
roll_offset = 0.0

rc_signal_lost = False
latest_rc = [1500, 1500, 1000, 1500, 1500]
rc_margin_deadband = 18
alert_voltage_threshold = 12.50

mission_planner_proc = None
excel_logger = None

def ensure_mission_planner_autoconnect():
    """Ensures Mission Planner's config.xml has the default UDP AutoConnect rule enabled for port 14550."""
    try:
        config_path = os.path.expandvars(r'%USERPROFILE%\Documents\Mission Planner\config.xml')
        if os.path.exists(config_path):
            with open(config_path, 'r', encoding='utf-8') as f:
                content = f.read()

            start_tag = '<AutoConnect>'
            end_tag = '</AutoConnect>'
            if start_tag in content and end_tag in content:
                idx1 = content.find(start_tag) + len(start_tag)
                idx2 = content.find(end_tag)
                json_str = content[idx1:idx2]
                autoconnect_list = json.loads(json_str)
                
                updated = False
                has_udp = False
                for item in autoconnect_list:
                    if item.get('Port') == 14550 and item.get('Protocol') == 'Udp' and item.get('Direction') == 'Inbound':
                        has_udp = True
                        if not item.get('Enabled'):
                            item['Enabled'] = True
                            updated = True
                    elif item.get('Protocol') in ['Serial', 'ComPort', 'Com']:
                        if item.get('Enabled'):
                            item['Enabled'] = False
                            updated = True
                if not has_udp:
                    autoconnect_list.insert(0, {
                        'Label': 'Mavlink default port',
                        'Enabled': True,
                        'Port': 14550,
                        'Protocol': 'Udp',
                        'Format': 'MAVLink',
                        'Direction': 'Inbound',
                        'ConfigString': ''
                    })
                    updated = True
                
                if updated:
                    new_json_str = json.dumps(autoconnect_list, indent=2)
                    new_content = content[:idx1] + new_json_str + content[idx2:]
                    with open(config_path, 'w', encoding='utf-8') as f:
                        f.write(new_content)
                    print("[Mission Planner Config] Configured UDP 14550 AutoConnect and disabled Serial COM scan.")
    except Exception as e:
        print(f"[Mission Planner Config Warning] Could not update config.xml: {e}")

class AsyncTelemetryLogger:
    """High-performance, non-blocking asynchronous telemetry logger writing pure real-time CSV."""
    def __init__(self, filename=None):
        if filename is None:
            self.filename = get_next_flight_log_filename()
        else:
            self.filename = filename if filename.endswith('.csv') else f"{filename}.csv"
            
        self.queue = queue.Queue(maxsize=10000)
        self.is_running = False
        self.worker_thread = None
        self.record_count = 0
        self.csv_file = None
        self.csv_writer = None
        self.headers = [
            "Record Number", "ESP32 Timestamp (ms)", "Elapsed Time (s)", "Packet Seq",
            "Pitch (deg)", "Roll (deg)", "Yaw (deg)",
            "Accel X (LSB)", "Accel Y (LSB)", "Accel Z (LSB)",
            "Accel X (g)", "Accel Y (g)", "Accel Z (g)", "Total Accel (g)",
            "Accel X (m/s^2)", "Accel Y (m/s^2)", "Accel Z (m/s^2)",
            "Gyro X (LSB)", "Gyro Y (LSB)", "Gyro Z (LSB)",
            "Gyro X (deg/s)", "Gyro Y (deg/s)", "Gyro Z (deg/s)",
            "RC1 Roll (us)", "RC2 Pitch (us)", "RC3 Throttle (us)", "RC5 Mode (us)",
            "Servo BR (us)", "Servo BL (us)", "Servo FR (us)", "Servo FL (us)", "ESC Throttle (us)",
            "Battery Voltage (V)", "Altitude (m)", "RC Signal Lost", "RC Data Received", "Flaperons Active",
            "Latitude", "Longitude", "Satellites", "Fix Type", "RSSI (dBm)", "SNR (dB)",
            "Flight Mode", "ESC Active", "Failsafe Stage",
            "Pitch Kp", "Pitch Ki", "Pitch Kd",
            "Roll Kp", "Roll Ki", "Roll Kd"
        ]

    def start(self):
        if self.is_running:
            return
        os.makedirs(os.path.dirname(self.filename), exist_ok=True)
        self.csv_file = open(self.filename, 'w', newline='', encoding='utf-8')
        self.csv_writer = csv.writer(self.csv_file)
        self.csv_writer.writerow(self.headers)
        self.csv_file.flush()
        print(f"[Telemetry Logger] New flight log started at: '{self.filename}'.")

        self.is_running = True
        self.worker_thread = threading.Thread(target=self._worker_loop, daemon=True)
        self.worker_thread.start()

    def log_row(self, row):
        if self.is_running:
            try:
                self.queue.put_nowait(row)
            except Exception:
                pass

    def _worker_loop(self):
        while self.is_running or not self.queue.empty():
            try:
                row = self.queue.get(timeout=0.1)
            except queue.Empty:
                continue

            if row is not None and self.csv_writer is not None:
                try:
                    self.csv_writer.writerow(row)
                    self.record_count += 1
                except Exception:
                    pass
                self.queue.task_done()

            # Flush sequentially to protect against data loss
            if (self.record_count % 10) == 0:
                try:
                    self.csv_file.flush()
                except Exception:
                    pass

    def stop(self):
        if not self.is_running:
            return
        self.is_running = False
        if self.worker_thread and self.worker_thread.is_alive():
            self.worker_thread.join(timeout=1.0)
        while not self.queue.empty():
            try:
                row = self.queue.get_nowait()
                if row is not None and self.csv_writer is not None:
                    self.csv_writer.writerow(row)
                    self.record_count += 1
                self.queue.task_done()
            except Exception:
                break
        if self.csv_file:
            try:
                self.csv_file.flush()
                self.csv_file.close()
            except Exception:
                pass
        print(f"[MANTA Ground Station] Final log saved to {self.filename} ({self.record_count} records).")

def kill_mission_planner():
    """Terminates Mission Planner process cleanly and kills any running instances."""
    global mission_planner_proc
    if mission_planner_proc is not None:
        try:
            mission_planner_proc.terminate()
        except Exception:
            pass
    try:
        subprocess.run(["taskkill", "/f", "/im", "MissionPlanner.exe"],
                       stdout=subprocess.DEVNULL, stderr=subprocess.DEVNULL)
    except Exception:
        pass

def global_shutdown(signum=None, frame=None):
    """Cleanly terminates Ground Station, saves Excel, closes Mission Planner, and exits immediately."""
    global active_serial_conn, excel_logger
    print("\n[MANTA Ground Station] Shutting down processes...")
    
    if active_serial_conn and active_serial_conn.is_open:
        try:
            active_serial_conn.close()
        except Exception:
            pass

    if excel_logger is not None:
        try:
            excel_logger.stop()
        except Exception:
            pass

    kill_mission_planner()
    print("[MANTA Ground Station] Terminated successfully.")
    os._exit(0)

def launch_mission_planner():
    """Ensures auto-connect settings and launches Mission Planner."""
    global mission_planner_proc
    ensure_mission_planner_autoconnect()
    mp_paths = [
        r'C:\Program Files (x86)\Mission Planner\MissionPlanner.exe',
        r'C:\Program Files\Mission Planner\MissionPlanner.exe',
        os.path.expandvars(r'%LOCALAPPDATA%\Apps\Mission Planner\MissionPlanner.exe'),
        os.path.expandvars(r'%USERPROFILE%\Desktop\Mission Planner.lnk')
    ]
    for p in mp_paths:
        if os.path.exists(p):
            try:
                mission_planner_proc = subprocess.Popen([p], stdout=subprocess.DEVNULL, stderr=subprocess.DEVNULL)
                print(f"[Mission Planner] Mission Planner launched automatically from: '{p}'")
                return True
            except Exception as e:
                print(f"[Mission Planner Launch Error] Failed to launch Mission Planner: {e}")

    print("[Mission Planner] MissionPlanner.exe path was not found automatically.")
    return False

def load_calibration():
    """Loads persistent local Ground Station parameters (horizon offsets, deadband alert, voltage cutoff) from JSON."""
    global pitch_offset, roll_offset, alert_voltage_threshold, rc_margin_deadband
    if os.path.exists(CALIB_FILE):
        try:
            with open(CALIB_FILE, 'r', encoding='utf-8') as f:
                data = json.load(f)
                pitch_offset = float(data.get('pitch_offset', 0.0))
                roll_offset = float(data.get('roll_offset', 0.0))
                if 'deadband' in data:
                    rc_margin_deadband = int(data.get('deadband', 18))
                if 'cutoff' in data:
                    alert_voltage_threshold = float(data.get('cutoff', 12.50))
        except Exception as e:
            print(f"[IMU Calibration Error] Failed to load calibration file: {e}")

def save_calibration():
    """Saves persistent local Ground Station parameters to JSON file (Simplex Downlink architecture)."""
    global pitch_offset, roll_offset, alert_voltage_threshold, rc_margin_deadband
    try:
        data = {}
        if os.path.exists(CALIB_FILE):
            try:
                with open(CALIB_FILE, 'r', encoding='utf-8') as f:
                    data = json.load(f)
            except Exception:
                data = {}
        data['pitch_offset'] = round(pitch_offset, 2)
        data['roll_offset'] = round(roll_offset, 2)
        data['deadband'] = int(rc_margin_deadband)
        data['cutoff'] = round(alert_voltage_threshold, 2)
        with open(CALIB_FILE, 'w', encoding='utf-8') as f:
            json.dump(data, f, indent=2)
    except Exception as e:
        print(f"[IMU Calibration Error] Failed to save calibration file: {e}")

def auto_find_com_port(preferred_port=None):
    """Detects available COM ports and selects the Ground Station ESP32 port."""
    if preferred_port:
        return preferred_port
    ports = list(serial.tools.list_ports.comports())
    if not ports:
        return None
    for p in ports:
        if "COM4" in p.device:
            return "COM4"
    for p in ports:
        if "COM6" in p.device:
            return "COM6"
    for p in ports:
        if "COM5" not in p.device:
            return p.device
    return ports[0].device


# ==============================================================================
#                       TELEMETRY & MAVLINK BRIDGE LOOP
# ==============================================================================

def run_bridge(port_name=None, launch_mp=True):
    """Main CLI execution loop for LoRa Telemetry & MAVLink Mission Planner Bridge."""
    global active_serial_conn, latest_estimated_voltage, latest_pitch, latest_roll, latest_yaw
    global latest_ax, latest_ay, latest_az, latest_gx, latest_gy, latest_gz
    global latest_ax_g, latest_ay_g, latest_az_g, latest_total_accel_g
    global latest_alt, latest_lat, latest_lon, latest_temp, latest_satellites, latest_fix_type, latest_rc
    global last_rssi, last_snr, rc_signal_lost, excel_logger

    load_calibration()
    port = auto_find_com_port(port_name)
    if not port:
        print("[Error] No COM port detected! Connect the Ground Station ESP32.")
        return

    print("=" * 60)
    print("      MANTA 5 Hz TELEMETRY & MISSION PLANNER BRIDGE")
    print("=" * 60)
    print(f"Ground Station COM Port  : {port} @ {DEFAULT_BAUD} baud")
    print(f"MAVLink UDP Bridge       : 127.0.0.1:14550")
    print("-" * 60)

    excel_logger = AsyncTelemetryLogger()
    excel_logger.start()

    try:
        ser = serial.Serial(port, DEFAULT_BAUD, timeout=0.01)
        active_serial_conn = ser
        print(f"[Connection] Successfully connected to {port}!")
    except Exception as e:
        print(f"[Connection Error] Failed to open {port}: {e}")
        return

    mav_conn = None
    if HAS_PYMAVLINK:
        try:
            mav_conn = mavutil.mavlink_connection('udpout:127.0.0.1:14550', source_system=1, source_component=1)
            print("[MAVLink] UDP link initialized to 127.0.0.1:14550.")
        except Exception as e:
            print(f"[MAVLink Warning] Failed to initialize MAVLink connection: {e}")

    if launch_mp:
        launch_mission_planner()

    raw_bytes_buffer = bytearray()
    buffer = ""
    last_mav_heartbeat = 0.0
    last_cli_print = 0.0
    last_system_time_tx = 0.0
    last_packet_rx_time = time.time()
    record_number = 1
    start_time = time.time()

    # Flight timer and state tracking
    cumulative_flight_time = 0.0
    last_flight_tick = start_time
    last_alt_calc = 0.0
    first_alt_sample = True
    last_alt_time = start_time
    filtered_climb_rate = 0.0
    estimated_airspeed = 0.0
    latest_flight_mode = 1
    latest_flaperon_active = False
    last_notified_mode = None
    last_notified_flaperon_active = None
    last_notified_rc_lost = None

    # Home Position tracking for Mission Planner Return-to-Home & Distance-to-Home
    home_position_set = False
    home_lat_e7 = 0
    home_lon_e7 = 0
    home_alt_mm = 0
    last_home_tx = 0.0

    print("\n[Active Telemetry - Simplex Downlink] Receiving LoRa packets from MANTA... (Press Ctrl+C to exit)\n")

    try:
        while True:
            # Safe serial read with error handling and auto-reconnect
            try:
                num_bytes = ser.in_waiting
                if num_bytes > 0:
                    raw_data = ser.read(num_bytes)
                    raw_bytes_buffer.extend(raw_data)

                    # Bound binary buffer to prevent unbounded memory growth
                    if len(raw_bytes_buffer) > 2048:
                        raw_bytes_buffer = raw_bytes_buffer[-512:]

                    # Extract binary telemetry packets (Magic header: 'MT' -> 0x4D, 0x54)
                    while len(raw_bytes_buffer) >= min(SUPPORTED_PACKET_SIZES):
                        header_idx = raw_bytes_buffer.find(b'MT')
                        if header_idx == -1:
                            if len(raw_bytes_buffer) > 0 and raw_bytes_buffer[-1] == 0x4D:
                                raw_bytes_buffer = raw_bytes_buffer[-1:]
                            else:
                                raw_bytes_buffer.clear()
                            break
                        elif header_idx > 0:
                            raw_bytes_buffer = raw_bytes_buffer[header_idx:]

                        # Try candidate sizes starting from longest supported packet down
                        decoded_pkt = None
                        matched_size = 0
                        for cand_size in SUPPORTED_PACKET_SIZES_DESC:
                            if len(raw_bytes_buffer) >= cand_size:
                                candidate = bytes(raw_bytes_buffer[:cand_size])
                                res = decode_telemetry(candidate)
                                if res is not None:
                                    decoded_pkt = res
                                    matched_size = cand_size
                                    break

                        if decoded_pkt is not None:
                            last_packet_rx_time = time.time()
                            raw_bytes_buffer = raw_bytes_buffer[matched_size:]
                            latest_pitch = decoded_pkt.get("pitch", latest_pitch)
                            latest_roll = decoded_pkt.get("roll", latest_roll)
                            latest_ax = decoded_pkt.get("accel_x", latest_ax)
                            latest_ay = decoded_pkt.get("accel_y", latest_ay)
                            latest_az = decoded_pkt.get("accel_z", latest_az)
                            latest_gx = decoded_pkt.get("gyro_x", latest_gx)
                            latest_gy = decoded_pkt.get("gyro_y", latest_gy)
                            latest_gz = decoded_pkt.get("gyro_z", latest_gz)

                            # Scale raw IMU counts to physical units
                            # MPU6050 @ +/- 2g range = 16384 LSB/g; Gyro @ +/- 1000 deg/s range = 32.8 LSB/(deg/s)
                            latest_ax_g = round(latest_ax / 16384.0, 3)
                            latest_ay_g = round(latest_ay / 16384.0, 3)
                            latest_az_g = round(-latest_az / 16384.0, 3)  # Inverted Z: upright flat resting is +1.0g
                            latest_total_accel_g = round(math.sqrt(latest_ax_g**2 + latest_ay_g**2 + latest_az_g**2), 2)
                            raw_bat = decoded_pkt.get("batteryVoltage", decoded_pkt.get("battery_v", None))
                            if raw_bat is not None and raw_bat > 0:
                                battery_voltage_history.append(raw_bat)
                                latest_estimated_voltage = round(sum(battery_voltage_history) / len(battery_voltage_history), 2)
                            raw_alt = decoded_pkt.get("alt", None)
                            gps_alt_val = decoded_pkt.get("gps_alt", None)
                            if raw_alt is not None and raw_alt != -1.0:
                                latest_alt = raw_alt
                            elif gps_alt_val is not None and gps_alt_val > 0:
                                latest_alt = gps_alt_val
                            pkt_lat = decoded_pkt.get("latitude", decoded_pkt.get("lat", 0.0))
                            pkt_lon = decoded_pkt.get("longitude", decoded_pkt.get("lon", 0.0))
                            if pkt_lat != 0.0 or pkt_lon != 0.0:
                                latest_lat = pkt_lat
                                latest_lon = pkt_lon
                            latest_satellites = decoded_pkt.get("satellites", decoded_pkt.get("sats", latest_satellites))
                            latest_fix_type = decoded_pkt.get("fix_type", decoded_pkt.get("fixType", latest_fix_type))
                            
                            rc_vals = decoded_pkt.get("rc", None)
                            if rc_vals and len(rc_vals) >= 4:
                                latest_rc = [rc_vals[0], rc_vals[1], rc_vals[2], 1500, rc_vals[3]]
                            else:
                                latest_rc = [
                                    decoded_pkt.get("rc1", latest_rc[0]),
                                    decoded_pkt.get("rc2", latest_rc[1]),
                                    decoded_pkt.get("rc3", latest_rc[2]),
                                    1500,
                                    decoded_pkt.get("rc5", latest_rc[4])
                                ]
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

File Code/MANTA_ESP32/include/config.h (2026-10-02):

#ifndef CONFIG_H
#define CONFIG_H

#include <Arduino.h>

// Hardware Pin Configuration
constexpr int PIN_BATTERY = 36; // ESP32 Pin VP / GPIO36
constexpr int PIN_ESC = 25;     // ESC Control Pin D25

// RC Receiver Configuration (FlySky FS-iA6B via i-Bus Protocol)
// PCB Port CH1 (GPIO 39 / Pin VN) with integrated resistive voltage divider (5V -> 3.3V)
constexpr int PIN_IBUS_RX = 39; // Hardware UART1 RX connected to FS-iA6B i-BUS SERVO port on PCB CH1
constexpr long IBUS_BAUD = 115200; // Standard FlySky i-Bus baud rate (8N1)


// Servo Output Pins (V-Tail Airframe)
constexpr int PIN_SERVO_BR = 13; // Back Right (GPIO13)
constexpr int PIN_SERVO_BL = 14; // Back Left (GPIO14)
constexpr int PIN_SERVO_FR = 27; // Front Right (GPIO27)
constexpr int PIN_SERVO_FL = 26; // Front Left (GPIO26)

// Control System Hysteresis Constants
constexpr uint8_t DEFAULT_RC_MARGIN_DEADBAND =
    4;  // Median filter already eliminates ISR jitter — 4us deadband prevents servo buzz without masking real stick input

// Servo Rotation Angle Limits & Conversion Factors (Default +/-25 degrees)
constexpr float US_PER_DEGREE =
    11.11f; // ~11.11us per degree (1000us total span / 90 deg)
constexpr uint8_t DEFAULT_SERVO_MAX_ANGLE_DEG =
    25; // Default +/- 25 degrees rotation limit (~278us from neutral: 1222us - 1778us)

// Flaperon Expanded Servo Deflection Limit (FR & FL surfaces when flaperons are engaged)
// Expanded from 25.0 deg (278 us) to 32.0 deg (~356 us) to allow full 20.0 deg flaps + roll authority
// without premature headroom choking, while retaining >= 100 us safe margin from the 2000 us ceiling.
constexpr uint8_t DEFAULT_FLAPERON_MAX_ANGLE_DEG = 32;
constexpr int FLAPERON_MAX_PULSE_LIMIT_US =
    (int)(DEFAULT_FLAPERON_MAX_ANGLE_DEG * US_PER_DEGREE + 0.5f); // ~356 us

// Flaperons (Landing Flaps) Parameters: Deflect both roll surfaces 20 degrees DOWN
constexpr float FLAPERON_DEFLECTION_DEG = 20.0f; // 20.0 deg DOWN max deflection for approach and landing
constexpr int FLAPERON_OFFSET_US =
    (int)(FLAPERON_DEFLECTION_DEG * US_PER_DEGREE + 0.5f); // ~222 us
// Servos FR & FL are physically mirrored:
// Deflection is calculated directly from each servo's trimmed neutral (spline/horn fit):
// For FL: negative PWM deflects DOWN (-222 us from trimmed neutral)
// For FR: positive PWM deflects DOWN (+222 us from trimmed neutral)
constexpr int FLAPERON_US_FR = +FLAPERON_OFFSET_US; // +222 us -> deflects right rolleron DOWN
constexpr int FLAPERON_US_FL = -FLAPERON_OFFSET_US; // -222 us -> deflects left rolleron DOWN

// Flaperon Throttle Governor Parameters:
// Flaperons deploy smoothly between 1500us and 1200us throttle (linear uniform transition).
// Above 1500us they are fully retracted (0 offset). Below 1200us they reach full 20.0 deg deflection.
constexpr int FLAPERON_THROTTLE_MAX_US = 1500; // >= 1500 us: Flaperons fully retracted (0 offset)
constexpr int FLAPERON_THROTTLE_MIN_US = 1200; // <= 1200 us: Flaperons fully deployed (20.0 deg DOWN)

// RC Stick Exponential Response Factor (0.0 = Linear, 1.0 = Pure Cubic; 0.35 = 35% Expo for center stick precision)
constexpr float RC_EXPO_FACTOR = 0.35f;

// MPU6050 I2C Pin Configuration
constexpr int PIN_SDA = 21; // MPU6050 SDA Pin D21
constexpr int PIN_SCL = 22; // MPU6050 SCL Pin D22

// GPS UART Pin Configuration (Hardware UART2)
constexpr int GPS_RX_PIN = 16;  // GPIO16 (RX2) connected to GPS TX
constexpr int GPS_TX_PIN = 17;  // GPIO17 (TX2) connected to GPS RX
constexpr long GPS_BAUD = 9600; // Standard NMEA GPS Baud Rate

// LoRa Pin Configuration (VSPI & Control)
constexpr int LORA_MOSI = 23;
constexpr int LORA_MISO = 19;
constexpr int LORA_SCK = 18;
constexpr int LORA_CS = 5;
constexpr int LORA_RST =
    -1; // RST not connected: avoids conflict with PIN_SERVO_BL on GPIO 14!
constexpr int LORA_DIO0 = 4;

// LoRa Long-Range High-Penetration Parameters (~3-5km range, SF8, CR 4/6, 20dBm)
constexpr long LORA_BAND = 433E6; // Frequency: 433 MHz
constexpr int LORA_TX_POWER =
    20; // 20 dBm (100mW max PA_BOOST output power for maximum range)
constexpr int LORA_SF = 8; // Spreading Factor 8 (+3dB sensitivity gain, high obstacle penetration)
constexpr long LORA_BW = 250E3; // Bandwidth 250 kHz (High frequency offset tolerance)
constexpr int LORA_CR = 6;      // Coding rate 4/6 (Hamming FEC for obstacle & interference immunity)
constexpr uint8_t LORA_SYNC_WORD = 0x12; // Matching LoRa Sync Word
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

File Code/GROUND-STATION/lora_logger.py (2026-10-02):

import sys
import time
import threading
import re
import os
import tkinter as tk
from tkinter import ttk, messagebox
import serial
import serial.tools.list_ports
import openpyxl
from openpyxl import Workbook
import json
from raw_lora_logger import AsyncRawLoRaLogger
from telemetry_codec import decode_telemetry, PACKET_SIZE, SUPPORTED_PACKET_SIZES, SUPPORTED_PACKET_SIZES_DESC

# Try importing matplotlib for embedded live plot
HAS_MATPLOTLIB = False
try:
    import matplotlib
    matplotlib.use("TkAgg")
    from matplotlib.figure import Figure
    from matplotlib.backends.backend_tkagg import FigureCanvasTkAgg
    HAS_MATPLOTLIB = True
except ImportError:
    HAS_MATPLOTLIB = False

DEFAULT_BAUD = 115200
EXCEL_FILE = 'lora_battery_log.xlsx'
DEFAULT_ALERT_VOLTAGE = 12.50

_SCRIPT_DIR = os.path.dirname(os.path.abspath(__file__))
_ROOT_DIR = os.path.abspath(os.path.join(_SCRIPT_DIR, '..', '..'))
if os.path.exists(os.path.join(_ROOT_DIR, 'imu_calibration.json')):
    CALIB_FILE = os.path.join(_ROOT_DIR, 'imu_calibration.json')
elif os.path.exists('imu_calibration.json'):
    CALIB_FILE = os.path.abspath('imu_calibration.json')
else:
    CALIB_FILE = os.path.join(_ROOT_DIR, 'imu_calibration.json')

def calculate_battery_voltage(raw_adc):
    """Calculates battery voltage matching the ESP32 polynomial equation:
       voltage = -0.000000884 * (raw_adc^2) + 0.008835 * raw_adc - 5.6904
    """
    voltage = -0.000000884 * (raw_adc ** 2) + 0.008835 * raw_adc - 5.6904
    return max(0.0, voltage)


class BatteryAnalyzerGUI:
    def __init__(self, root, shared_serial=None):
        self.root = root
        self.root.title("MANTA - LoRa Battery Analyzer & Logger")
        self.root.geometry("820x680")
        self.root.minsize(720, 580)

        # State Variables — shared_serial allows reusing a connection opened externally
        self.serial_conn = shared_serial
        self.is_connected = shared_serial is not None and shared_serial.is_open
        self.is_logging = False
        self.read_thread = None

        self.start_time = None
        self.timestamps = []
        self.voltages = []
        self.raw_adcs = []

        self.last_rssi = "N/A"
        self.last_snr = "N/A"
        self.current_voltage = 0.0
        self.current_adc = 0.0
        self.record_number = 1
        self.last_excel_save = 0.0

        # Last Known Calibration State for Change Logging
        self.last_angle = 30
        self.last_deadband = 18
        if os.path.exists(CALIB_FILE):
            try:
                with open(CALIB_FILE, 'r', encoding='utf-8') as f:
                    c_data = json.load(f)
                    if 'deadband' in c_data:
                        self.last_deadband = max(1, min(50, int(c_data['deadband'])))
            except Exception:
                pass
        self.last_trims = [0, 0, 0, 0]
        self.last_inv = [0, 0, 0, 0]
        self.last_alert_voltage = 12.50
        self.last_lora_power = 14
        self.last_servo_interval = 50
        self.last_manta_ch5 = 1500  # Default: Normal Flight Mode
        self.last_received_ack = None
        self.pending_config_commands = []  # Queued commands until Calibration Mode (CH5 > 1900) is active

        # Excel State
        self.wb = None
        self.ws = None

        # Theme Colors (Dark Theme)
        self.BG_COLOR = "#1e1e2e"
        self.CARD_BG = "#2a2a3c"
        self.TEXT_COLOR = "#cdd6f4"
        self.SUBTEXT_COLOR = "#a6adc8"
        self.ACCENT_GREEN = "#a6e3a1"
        self.ACCENT_RED = "#f38ba8"
        self.ACCENT_BLUE = "#89b4fa"
        self.ACCENT_YELLOW = "#f9e2af"
        self.ACCENT_CYAN = "#94e2d5"
        self.GRID_COLOR = "#313244"
        self.LOG_BG = "#11111b"

        self.root.configure(bg=self.BG_COLOR)
        self.async_raw_logger = AsyncRawLoRaLogger()

        self._configure_styles()
        self._build_ui()
        self.refresh_ports()
        # If we already have a shared connection, update UI to reflect connected state
        if self.is_connected:
            port_name = self.serial_conn.port
            self.btn_connect.config(text="DISCONNECT", bg=self.ACCENT_RED)
            self.lbl_status.config(text=f"Connected ({port_name})", fg=self.ACCENT_GREEN)
            self.port_combo.set(port_name)
            if shared_serial is None:
                self.read_thread = threading.Thread(target=self._read_serial_loop, daemon=True)
                self.read_thread.start()
            self.start_logging()
        self._update_raw_logger_ui()

    def _configure_styles(self):
        style = ttk.Style()
        style.theme_use("clam")
        style.configure(".", background=self.BG_COLOR, foreground=self.TEXT_COLOR, font=("Segoe UI", 10))
        style.configure("TCombobox", fieldbackground=self.CARD_BG, background=self.CARD_BG, foreground=self.TEXT_COLOR)
        style.map("TCombobox", fieldbackground=[("readonly", self.CARD_BG)], foreground=[("readonly", self.TEXT_COLOR)])

    def _build_ui(self):
        # --- HEADER ---
        header_frame = tk.Frame(self.root, bg=self.BG_COLOR, pady=10, padx=20)
        header_frame.pack(fill=tk.X)

        title_lbl = tk.Label(
            header_frame, text="BATTERY ANALYZER (LoRa)",
            font=("Segoe UI", 18, "bold"), bg=self.BG_COLOR, fg=self.ACCENT_CYAN
        )
        title_lbl.pack(anchor="w")

        subtitle_lbl = tk.Label(
            header_frame, text="Real-time Voltage vs Time Plotter & Excel Data Logger",
            font=("Segoe UI", 9, "italic"), bg=self.BG_COLOR, fg=self.SUBTEXT_COLOR
        )
        subtitle_lbl.pack(anchor="w")
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

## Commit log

2026-06-25 refactor: restructure repository folders and update project roadmap
    [MANTA.kicad_pcb, MANTA.kicad_sch]
2026-06-30 Update electronics for hardware compatibility
    - Updated the schematic and KiCad project to align with the physical hardware purchased.
    - Replaced generic connectors with specific 2.54mm pitch vertical pin headers (1x07 and 1x02) for the ESP32 and power distribution modules.
    - Refactored power routing and replaced symbols (adjusting GND, +15V, and +5V).
    - Updated designators (e.g., ESP32-LEFT1, ESP32-RIGHT1, EXTRA_ENERGY_15V1) to correctly match the interfaces of the new physical components.
    [MANTA.kicad_sch]
2026-06-30 Update electronics schematic
    [MANTA.kicad_sch]
2026-07-04 general fixes - todo: split into 2 boards <= 10mm
    [MANTA.kicad_pcb, MANTA.kicad_sch]
2026-07-04 splited into 2 boards: power and logic. finished the component position on the power pcb
    [MANTA.kicad_pcb, MANTA.kicad_sch]
2026-07-09 final pcb boards design
    [MANTA-B_Cu.gbr, MANTA-B_Mask.gbr, MANTA-B_Silkscreen.gbr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]
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2026-07-17 docs: update hardware roadmap, document PCB shield architecture, and add media previews
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2026-07-19 docs: update PCB power routing preview image and ignore KiCad lock files
2026-07-29 feat(battery): calibrate raw ADC voltage sensor and update roadmap
    - Experimentally determined raw ADC voltage sensor conversion function in ESP32 firmware for accurate battery voltage readings
    - Standardized code, UI strings, and comments to English across battery monitor files
    - Organized battery monitor sketch into proper Arduino folder structure (Code/Battery_Monitor/battery_monitor/)
    - Updated README.md status and Phase 2 roadmap: marked raw voltage sensor calibration as completed [x] and set next objective to battery discharge curve characterization under load
    [registo_bateria.xlsx]
2026-08-02 feat(battery): update battery voltage sensor analysis dataset and logger calibration
    [registo_bateria.xlsx, voltage_sensor_analysis.xlsx]
2026-08-02 ci: add GitHub Actions CI workflow and local automated ground truth test runner
2026-08-02 feat(lora): add initial LoRa bidirectional telemetry link between aircraft and ground station
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2026-08-07 doc(readme): update README with manufactured PCB & ground station hardware images and layout descriptions
2026-08-09 test(ci): add CI/CD compilation tests for MANTA firmware and Ground Station code
2026-08-11 feat(firmware): refactor ESP32 architecture and add sensor drivers
    Modularize ESP32 flight controller codebase with dedicated modules for MPU6050 IMU, BMP280 barometer, GPS, RC receiver pulse decoding, V-Tail control surfaces, and binary telemetry encoder.
2026-08-11 feat(ground-station): add MANTA Mission Planner GUI and binary telemetry decoder
    Add Python MANTA Mission Planner GUI application, binary telemetry decoder matching ESP32 telemetry codec, LoRa loggers, and updated ground station ESP32 firmware receiver code.
    [registo_manta_telemetry.xlsx]
2026-08-11 refactor(vision-sim): update PID flight simulator and CV test scripts
    Update PyQt PID flight simulator example GUI and refine MobileNet + KNN visual localization test scripts.
2026-08-11 chore(data): add IMU calibration config and flight telemetry logs
    Add static MPU6050 IMU calibration offsets configuration and raw LoRa telemetry logs captured during flight testing.
    [registo_manta_telemetry.xlsx]
2026-08-11 docs(readme): refine flight testing status, sensor debugging, and fly-by-wire roadmap
    Update README with refined language reflecting maiden flight completion, ongoing pilot confidence flight tests, sensor debugging, EMI testing completion, and upcoming fly-by-wire stabilization work.
2026-08-11 docs(readme): update project roadmap phases and flight control status
    Update project roadmap in README.md with Phase 3 (Flight Control & PID Stabilization), Phase 4 (Autonomous Waypoint Navigation), and Phase 5 (Onboard Vision & Raspberry Pi integration), adding dedica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
2026-08-16 feat(flight-control): enhance IMU Mahony AHRS fusion, roll envelope assist, and multi-version LoRa telemetry
    - IMU & Attitude Estimation:
    * Integrate 6-axis Mahony AHRS quaternion fusion with adaptive acceleration weighting (Kp=0.40, Ki=0.01) to eliminate steady-state drift.
    * Update calibrated level mounting trim offsets to -9.2 deg pitch and -1.9 deg roll for true zero-level attitude alignment.
    * Direct quaternion initialization from initial gravity vector upon boot.
    - Flight Control & Assisted Mode:
    * Implement intelligent roll envelope protection assist active when CH5 == 2000:
    - Linear authority attenuation into the bank angle from 0 deg (+/-20 deg) down to 60 deg (0 deg).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
    [manta_imu_calibration_log.csv, registo_bateria.xlsx, registo_manta_telemetry.xlsx]
2026-08-19 fix(telemetry): optimize LoRa link with SF8 and non-blocking background Excel logging
    - Upgrade LoRa Spreading Factor from SF7 to SF8 (+2.5dB noise margin, SNR down to -10dB) on both MANTA ESP32 and Ground Station.
    - Implement AsyncExcelTelemetryLogger in MANTA_MISSION_PLANNER.py with background worker thread, eliminating 1.5s-5.4s periodic main loop stalls.
    - Make Ground Station ESP32 LoRa RX re-enable immediate and non-blocking by removing Serial.flush().
    - Verified 100% pass across all 41 CI/CD tests.
    [MANTA_MISSION_PLANNER.py, config.h, main.cpp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]
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2026-08-30 feat(flight): update MANTA firmware with median filtering, trimmed neutrals, and mission planner GUI
    [MANTA.kicad_sch]
2026-09-07 feat(flight-control): Roll-only FBW PI-D, receiver filtering, CH5 calibration, and telemetry codec
    - control: Roll-only PI-D control (Pitch PID completely deactivated for anti-stall safety, pitch remains 100% manual direct in all modes)
    - control: implement CH5 Schmitt-trigger hysteresis and debounce for modes 1-3, roll assist / extremum seeking, soft throttle ceiling, and trimmed neutrals
    - telemetry: update 61-byte packet codec with dynamic PID gains (pitch gains at 0.00), active flight modes, and Ground Station logging/buzzer support
    - ground station: add buzzer feedback, tune_pid_sysid tool, and telemetry logger sync
    - tests: add comprehensive test suites for CH5 decoding, buzzer, and FB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
    [voltage_sensor_analysis.xlsx]
2026-09-10 stable version PIDs: Pitch (Kp=5.0, Ki=2.5, Kd=0.45), Roll (Kp=15.0, Ki=5.0, Kd=1.5), flaperon governor, IMU offsets and 61-byte telemetry codec
    - Pitch PI-D calibrated to Kp=5.00, Ki=2.50, Kd=0.450
    - Roll PI-D calibrated to Kp=15.00, Ki=5.00, Kd=1.500
    - Configured flaperon landing governor (15 deg DOWN) with linear throttle governor (1200-1500us) and roll priority anti-saturation
    - IMU mounting offsets: Pitch +9.2 deg, Roll +4.4 deg
    - FBW pitch limit capped at 25 deg (anti-stall) and anti-windup clamped at 50 us
    - Pure simplex telemetry packet updated to 61 bytes with flight mode and dynamic PID gains
    - Ground station buzzer feedback on mode changes and telemetry sync
    - Regression te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
    [MANTA_MISSION_PLANNER.py, config.h, control.cpp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]
2026-09-10 feat(control): expand PID integral authority range from 50us to 100us
    - Expanded MAX_INTEGRAL_PULSE_US from 50.0us to 100.0us in config.h
    - Kept Ki gains unchanged (Pitch Ki=2.50, Roll Ki=5.00) while providing +/-9.0 deg trim authority
    - Prevents steady-state attitude droop while preserving 178us (64%) dynamic headroom for P and D terms
    - Updated anti-windup clamping unit tests in test_fbw_pid_control.py (135 tests passing)
    [config.h, test_fbw_pid_control.py]
2026-09-10 refactor(ci): organize CI/CD test suites, categorize verification steps and improve naming
    - Renamed test_audit_fixes.py -> test_flight_safety_and_sysid.py and updated class to TestFlightSafetyAndSysID
    - Created pytest.ini with standard configurations and registered markers
    - Updated .github/workflows/ci.yml with descriptive workflow name (MANTA Avionics CI/CD Pipeline) and 5 categorized test verification steps
    - Upgraded run_tests.py with category filtering (--category), descriptions (--list), and clear reports
    - Verified 100% of 135 unit tests pass cleanly
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2026-10-02 feat: flight validation with calibrated PIDs, Raspberry Pi onboard recording and restructured documentation
    - Restructure README.md showcasing flight test validation, calibrated PIDs, and companion computer video pipeline
    - Add clickable onboard flight video banner linking to YouTube footage starting at 1:30 min
    - Add optimized pre-flight field inspection photo and physical assembled electronics stack
    - Document PI-D closed-loop control, surface trims, flaperons governor (20 deg down) with anti-saturation headroom scaling
    - Document Raspberry Pi 3 A+ autonomous boot stack, RF cutoff, and power-loss-immune MKV recording
    - Add Ground Station flight replay simulator and GPS auto-pin probing
    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
    [MANTA.kicad_pcb]
2026-10-02 fix(ci): add .gitattributes, resolve pymavlink/pandas imports, and fix Unix LF line endings
    - Add .gitattributes enforcing strict LF line endings for .sh and .service files
    - Ensure Code/MANTA_PI scripts and services maintain Unix LF endings on all platforms
    - Add safe fallback imports and future annotations in replay_flight_mission_planner.py
    - Add skipif guards and mock log fallback in test_flight_replay_simulator.py
    - Update ci.yml to install numpy, pandas, and pymavlink and run complete test suite
    [replay_flight_mission_planner.py, test_flight_replay_simulator.py]
